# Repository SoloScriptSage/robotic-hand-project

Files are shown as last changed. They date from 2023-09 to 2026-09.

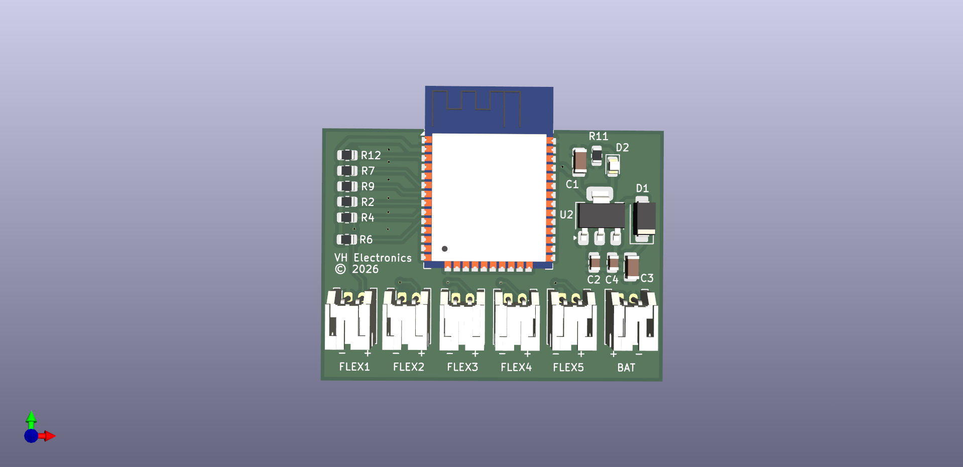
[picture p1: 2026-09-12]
hardware/schematics/transmitter/robotic_hand.png

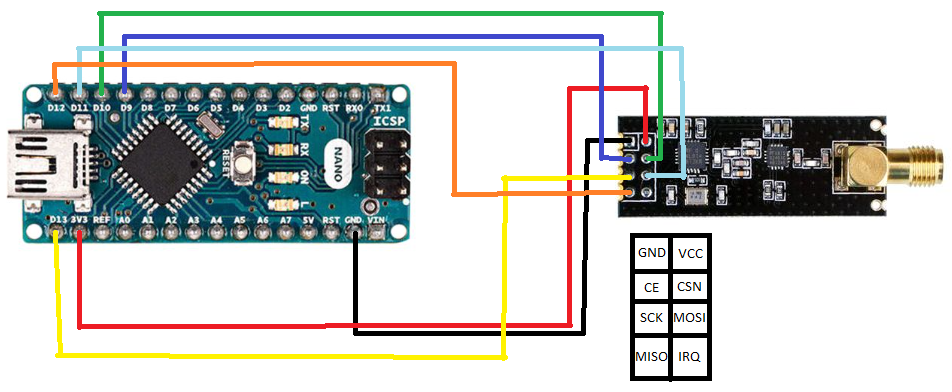
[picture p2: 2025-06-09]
hardware/assembly-guides/nrf-arduino-nano.png

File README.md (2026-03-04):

# 🤖 Robotic Hand Project

A wireless gesture-controlled robotic hand built with Arduino, flex sensors, and NRF24L01 radio modules. A glove fitted with flex sensors captures hand movements and transmits them wirelessly to a 3D-printed robotic hand, which mirrors the gestures in real time via servo motors.

Originally developed as an open-source prosthetic research platform.

---

## 📸 Demo

Robotic Hand Demo

---

## ✨ Features

- Real-time wireless gesture control via NRF24L01 (250KBPS, ~100m range)
- 5-finger articulation using MG996R servo motors
- Flex sensor glove for intuitive hand tracking
- Per-finger calibration support
- Simple, hackable codebase — easy to extend

---

## 📁 Repository Structure

```
robotic-hand-project/
│
├── firmware/
│   ├── transmitter/        ← glove Arduino code
│   ├── receiver/           ← hand Arduino code
│   ├── test_sensors/       ← flex sensor calibration helper
│   └── servo_test/         ← servo sweep test
│
├── hardware/
│   ├── schematics/         ← wiring diagrams
│   ├── pcb/                ← PCB files
│   ├── mechanical/
│   │   └── robotic-hand-stls/  ← 3D print files
│   ├── assembly-guides/    ← step by step assembly
│   ├── datasheets/         ← component datasheets
│   └── BOM.md              ← full bill of materials
│
├── docs/
│   ├── calibration.md      ← flex sensor calibration guide
│   └── troubleshooting.md  ← common issues and fixes
│
├── images/                 ← photos and demo gifs
├── .gitignore
├── LICENSE
└── README.md
```

---

## 🛠️ Materials

Full bill of materials with component links and prices → [`hardware/BOM.md`](hardware/BOM.md)

---

## 🗺️ Schematics

Wiring diagrams for both transmitter and receiver → [`hardware/schematics/`](hardware/schematics/)

> ⚠️ Power the NRF24L01 modules from the **3.3V pin only** — they are not 5V tolerant.

---

## 🖨️ 3D Model

The hand structure is sourced from [Viral Science](https://www.viralsciencecreativity.com/post/arduino-flex-sensor-controlled-robot-hand). Print files are available in [`hardware/mechanical/robotic-hand-stls/`](hardware/mechanical/robotic-hand-stls/).

Print settings:
- Material: PLA or PETG
- Infill: 20–30%
- Supports: Yes (for finger joints)

---

## ⚙️ Setup

### 1. Clone the repository
```bash
git clone https://github.com/SoloScriptSage/robotic-hand-project.git
```

### 2. Install Arduino libraries
In Arduino IDE go to **Sketch → Include Library → Manage Libraries** and install:
- `RF24` by TMRh20
- `Servo` (built-in)

### 3. Assemble the hardware
- Print and assemble the 3D hand following the guides in [`hardware/assembly-guides/`](hardware/assembly-guides/)
- Wire flex sensors to the glove according to the schematics
- Wire servos to the receiver board according to the schematics

### 4. Calibrate the flex sensors
Follow the step-by-step guide → [`docs/calibration.md`](docs/calibration.md)

### 5. Flash the firmware
- Flash [`firmware/transmitter/transmitter.ino`](firmware/transmitter/transmitter.ino) to the **glove Arduino**
- Flash [`firmware/receiver/receiver.ino`](firmware/receiver/receiver.ino) to the **hand Arduino**

### 6. Test
- Flash [`firmware/servo_test/servo_test.ino`](firmware/servo_test/servo_test.ino) to verify all servos sweep correctly
- Power both Arduinos and open Serial Monitor — you should see sensor values on the transmitter and matching received values on the receiver

---

## 💻 Code Overview

| File | Description |
|---|---|
| `transmitter.ino` | Reads flex sensors, maps to servo angles, transmits via NRF24L01 |
| `receiver.ino` | Receives data, writes angles to servo motors |
| `test_sensors.ino` | Prints raw flex sensor values for calibration |
| `servo_test.ino` | Sweeps all servos 0→180→0 for hardware testing |

---

## 🧪 Testing

Sensor Testing
Bending Testing

---

## 📖 Docs

- [Calibration Guide](docs/calibration.md)
- [Troubleshooting](docs/troubleshooting.md)

---

## 🚀 Roadmap

- [ ] Per-finger calibration via Serial Monitor wizard
- [ ] Haptic feedback on glove (vibration motors)
- [ ] NRF24L01 external antenna for extended range
- [ ] Replace flex sensors with IMU-based gesture recognition
- [ ] Full prosthetic enclosure design
- [ ] Support for wrist rotation (6th servo)

---

## 🙏 Acknowledgments

- [Viral Science](https://www.viralsciencecreativity.com/post/arduino-flex-sensor-controlled-robot-hand) for the 3D hand model
- [TMRh20](https://github.com/nRF24/RF24) for the RF24 library
- The open-source Arduino community

---

## 📄 License

This project is open-source under the [MIT License](LICENSE).

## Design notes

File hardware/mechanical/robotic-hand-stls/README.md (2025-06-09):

# 🖨️ Robotic Hand – STL Files

This folder contains the 3D printable parts (STL format) used to assemble the robotic hand mechanism.

---

## 📁 Included Files

| File Name | Description |
|---|---|
| `Arm.stl` | Forearm base part |
| `Arm_Cover.stl` | Cover or mount for forearm |
| `Finger_Thumb.stl` | Thumb finger segment |
| `Finger_Index.stl` | Index finger segment |
| `Finger_Middle.stl`  | Middle finger segment |
| `Finger_Ring.stl` | Ring finger segment |
| `Finger_Pinky.stl` | Pinky finger segment |
| `Left_Hand.stl` | Complete left hand model |
| `Right_Hand.stl` | Complete right hand model  |

> 🔒 `.DS_Store` is a macOS system file and can be ignored or deleted.

---

## 📥 Credit & Attribution

The mechanical design of the robotic hand was sourced from **Viral Science**.

🔗 [Arduino Flex Sensor Controlled Robotic Hand – Viral Science](https://www.viralsciencecreativity.com/post/arduino-flex-sensor-controlled-robot-hand)

We give full credit to the Viral Science team for sharing their design with the maker community. This STL collection is redistributed here for educational and prototyping purposes.

---

## 🛠️ Printing & Assembly Tips

- **Material:** PLA or PETG recommended
- **Infill:** 30–50% for durability
- **Supports:** Use if needed (especially for fingers)
- **Scale:** Ensure correct scale before printing
- **Assembly:** Use fish wire to connect fingers to servo horns; secure with a glue gun where necessary

---

## 🧠 Integration

These mechanical parts are designed to be used with:

- **MG996R Servo Motors**
- **Arduino Nano**
- **NRF24L01 wireless modules**
- **Flex sensors**

Refer to the main project’s BOM and wiring diagrams for details.

---

**Note:** All mechanical parts should be tested and tweaked for fit with your specific hardware and 3D printer tolerances.

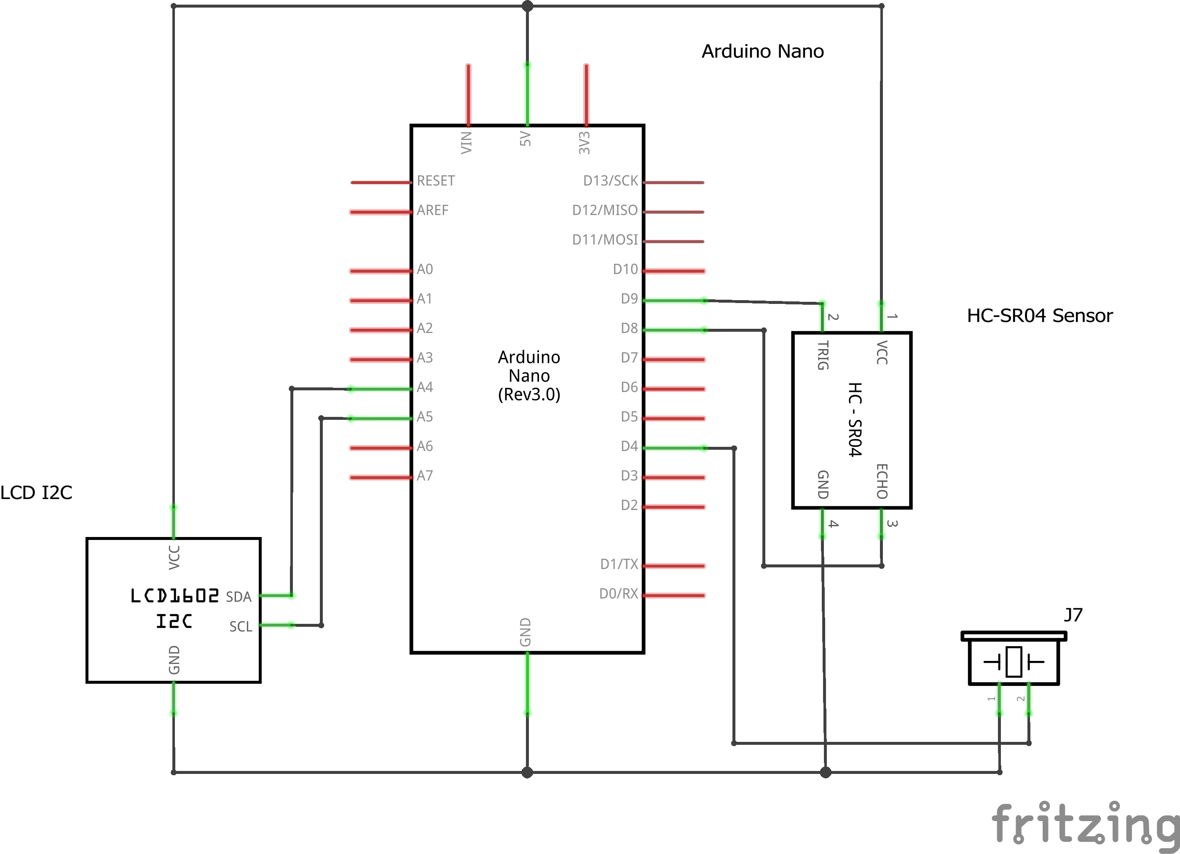
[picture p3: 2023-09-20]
images/distance_schematic.jpg

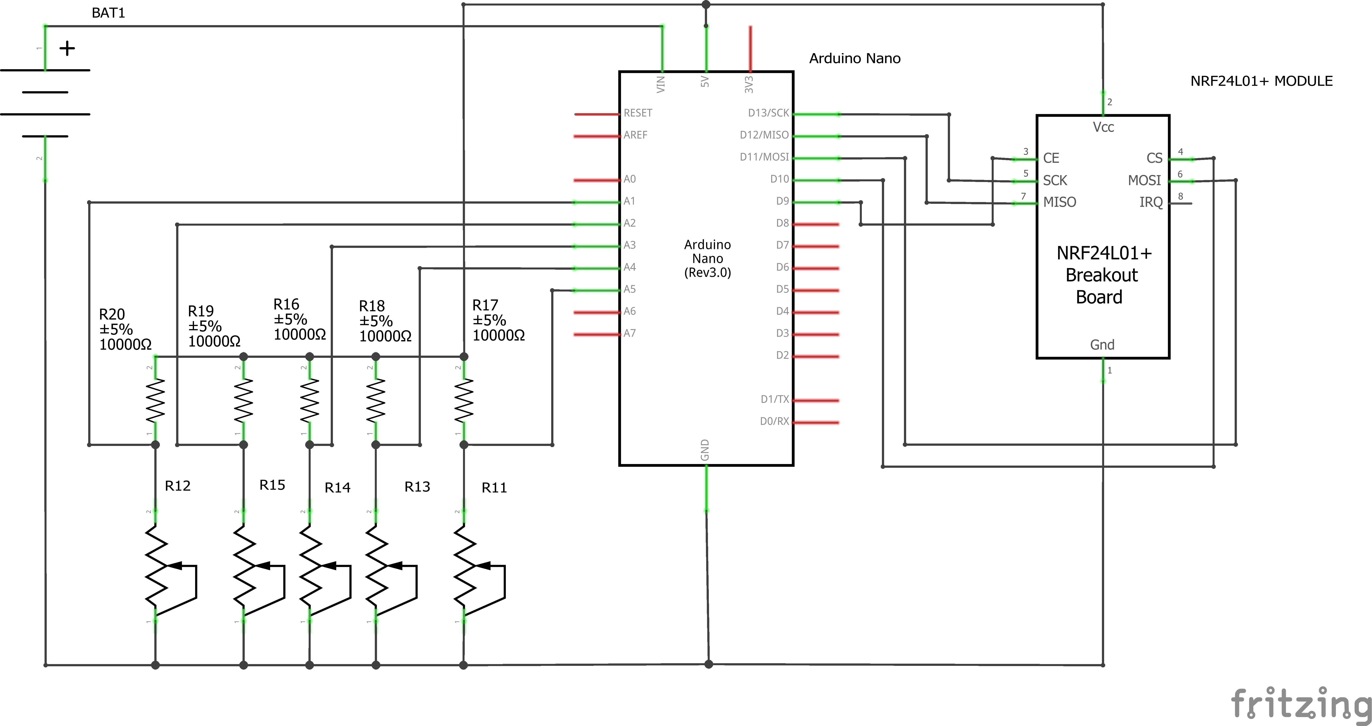
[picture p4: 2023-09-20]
images/transmitter_schematic.png

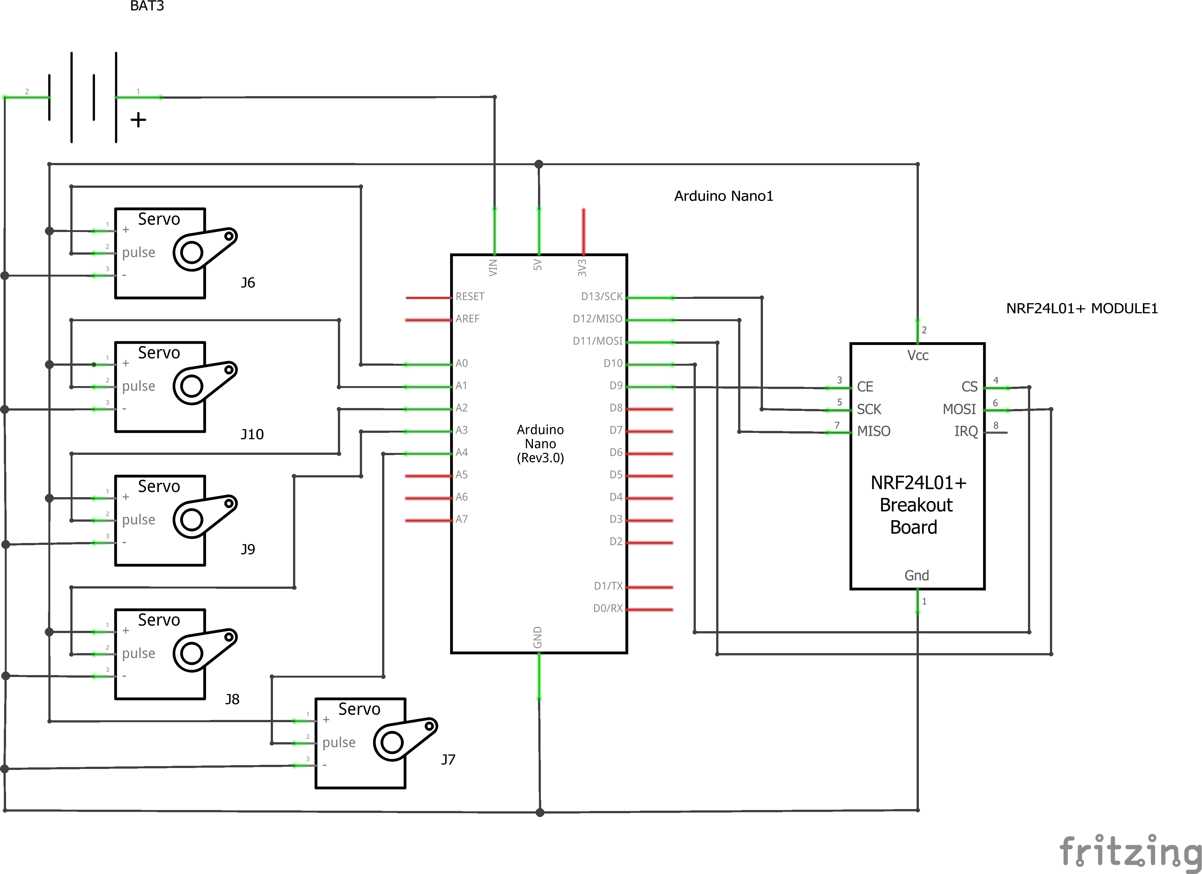
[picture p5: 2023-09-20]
images/receiver_schematic.jpg

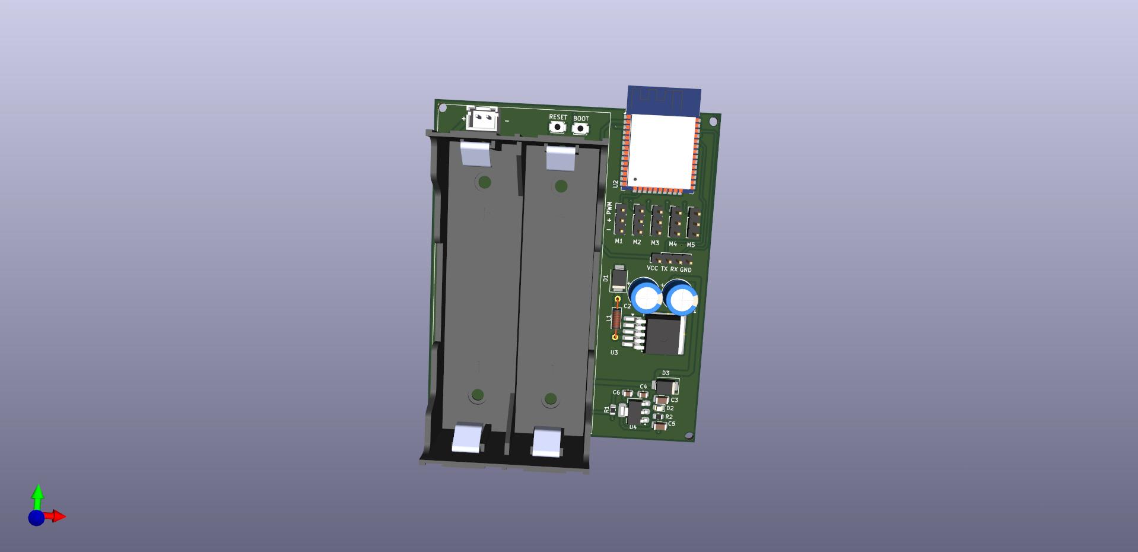
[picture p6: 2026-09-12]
hardware/schematics/reciever/robotic_hand_recievier.jpg

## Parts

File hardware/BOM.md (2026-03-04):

# Bill of Materials

Full component list for the robotic hand project. Includes both the glove (transmitter) and the robotic hand (receiver).

---

## Electronics

| # | Component | Description | Qty | Unit Price (est.) | Link |
|---|---|---|---|---|---|
| 1 | Arduino Uno / Mega | Microcontroller — one for glove, one for hand | 2 | ~$10 | [Amazon](https://a.co/d/7hcBaU4) |
| 2 | NRF24L01+ Module | 2.4GHz wireless transceiver | 2 | ~$2 | [Amazon](https://a.co/d/2pLEXYt) |
| 3 | Flex Sensor 2.2" | Bend-sensitive resistor for each finger | 5 | ~$8 | [Amazon](https://a.co/d/0HHEU9b) |
| 4 | MG996R Servo Motor | High-torque servo for finger actuation | 5 | ~$5 | [Amazon](https://a.co/d/9qywIPb) |
| 5 | 10kΩ Resistor | Pull-down resistor for flex sensor voltage divider | 5 | ~$0.10 | [Amazon](https://a.co/d/1EXjHHf) |
| 6 | LiPo 7.4V / NiMH 7.2V Battery | Power supply for servo side | 1 | ~$15 | [Amazon](https://a.co/d/2NYQ9gW) |
| 7 | Jumper Wires | M-M and M-F for connections | 1 set | ~$5 | [Amazon](https://a.co/d/2u9a7ZK) |

---

## Mechanical

| # | Component | Description | Qty | Link |
|---|---|---|---|---|
| 1 | 3D Printed Hand Parts | STL files in [`hardware/mechanical/robotic-hand-stls/`](mechanical/robotic-hand-stls/) | 1 set | — |
| 2 | Fish Wire | Finger tendon line | ~1m | [Amazon](https://a.co/d/iEQPEsA) |
| 3 | Hot Glue | For securing components | — | [Amazon](https://a.co/d/2u9a7ZK) |
| 4 | M2/M3 Screws | For mounting servos to hand frame | ~20 | — |

---

## Tools Required

| Tool | Notes |
|---|---|
| 3D Printer | PLA or PETG recommended |
| Soldering Iron | For secure sensor connections |
| Hot Glue Gun | For cable management and securing parts |
| Multimeter | For troubleshooting connections |
| Arduino IDE | Version 2.x recommended |

---

## Notes

- NRF24L01 modules must be powered from **3.3V**, not 5V
- MG996R servos draw significant current — power them from the battery directly, not from Arduino 5V
- A capacitor (100µF) across the NRF24L01 power pins helps stabilize the module

---

*Schematics are available in [`hardware/schematics/`](schematics/)*

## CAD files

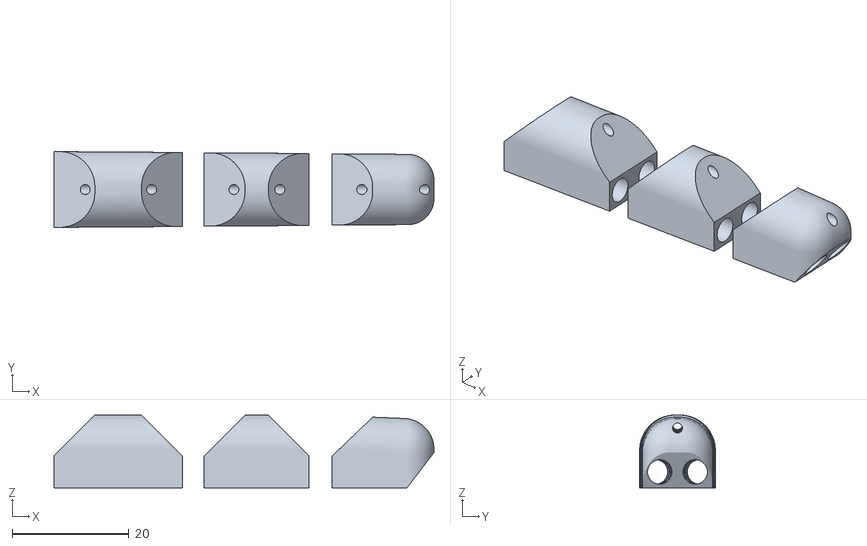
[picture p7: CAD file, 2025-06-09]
hardware/mechanical/robotic-hand-stls/Finger_Pinky.stl
65.2 x 13.0 x 12.5

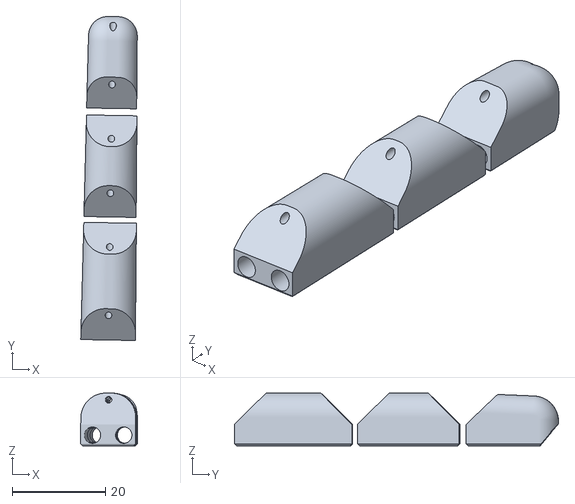
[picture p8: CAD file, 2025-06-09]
hardware/mechanical/robotic-hand-stls/Finger_Index.stl
12.1 x 69.4 x 11.3

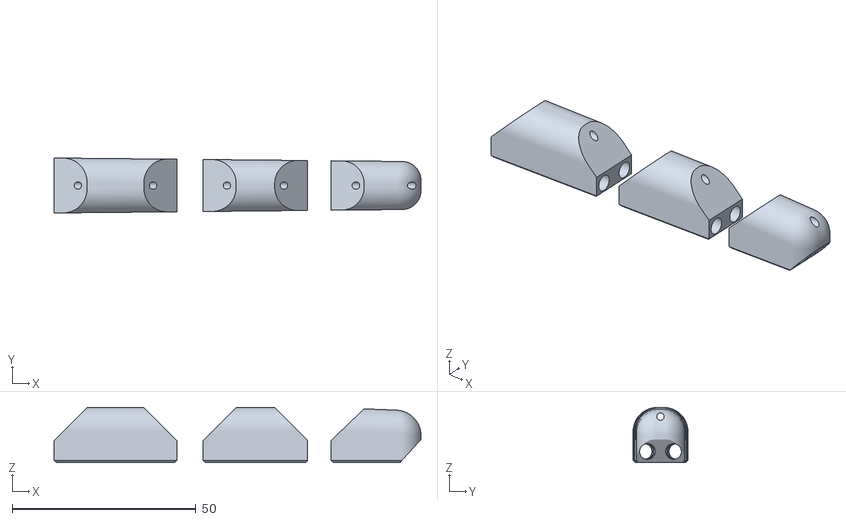
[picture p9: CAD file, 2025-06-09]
hardware/mechanical/robotic-hand-stls/Finger_Middle.stl
100.0 x 15.0 x 15.0

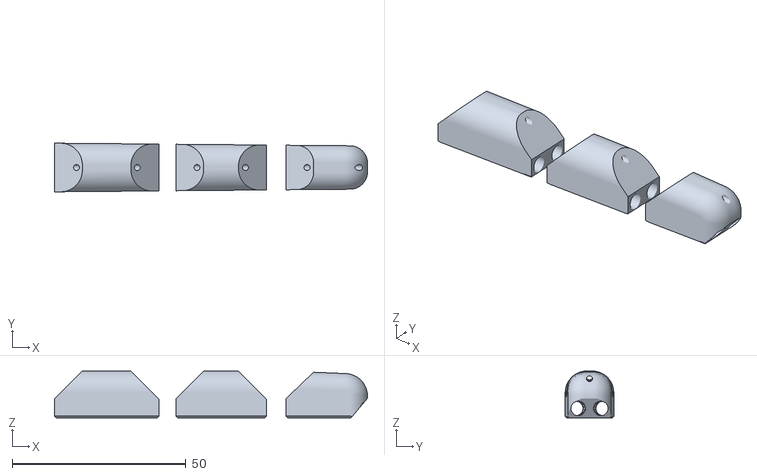
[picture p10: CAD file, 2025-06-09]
hardware/mechanical/robotic-hand-stls/Finger_Ring.stl
90.0 x 14.0 x 13.5

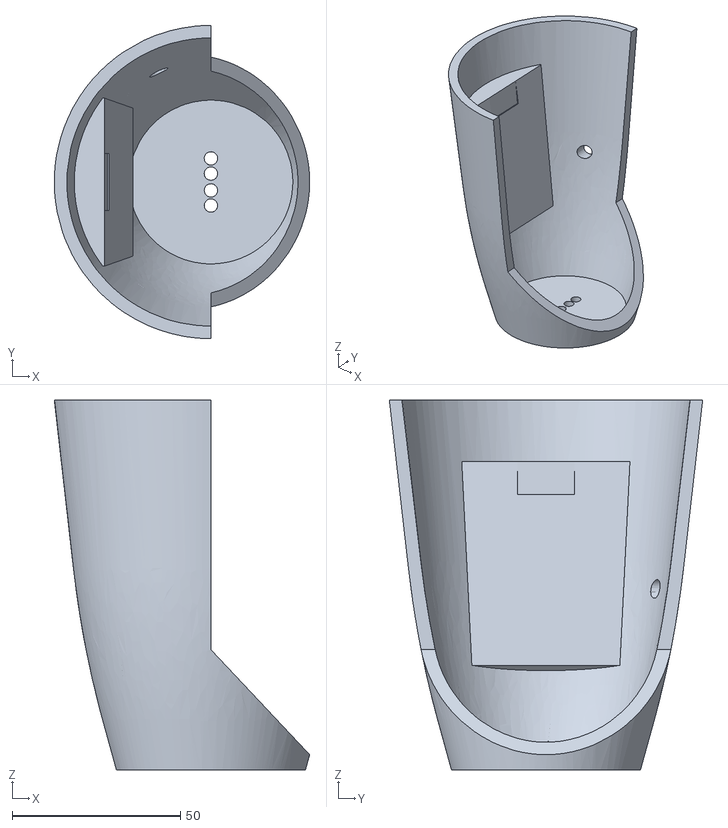
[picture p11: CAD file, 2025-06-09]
hardware/mechanical/robotic-hand-stls/Arm.stl
75.9 x 93.1 x 109.9

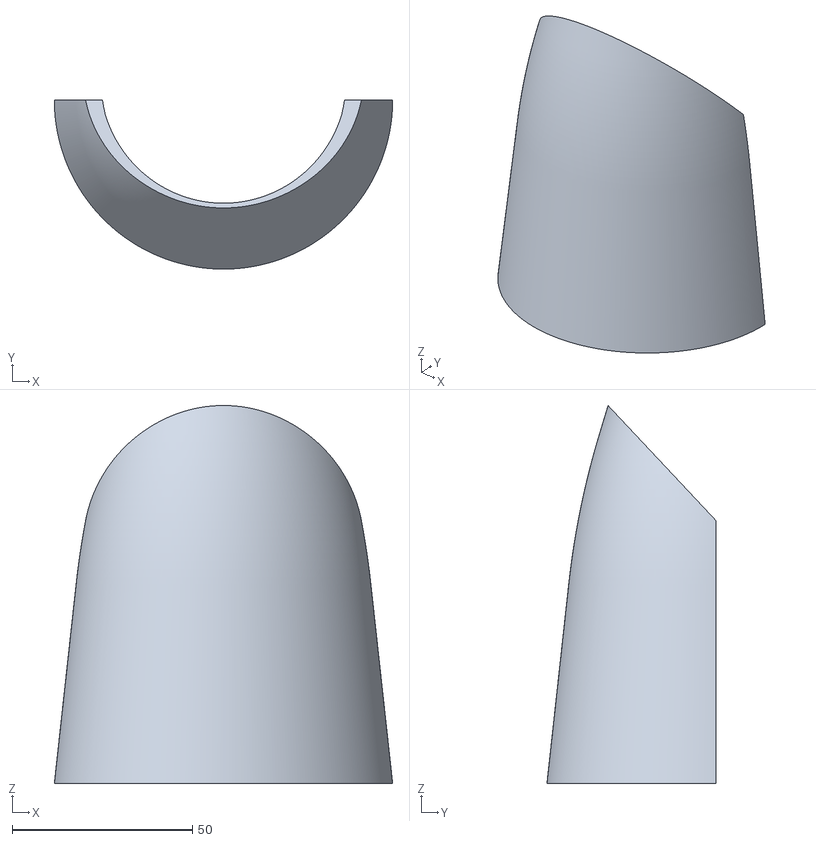
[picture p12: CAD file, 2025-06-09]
hardware/mechanical/robotic-hand-stls/Arm_Cover.stl
94.0 x 47.0 x 105.0

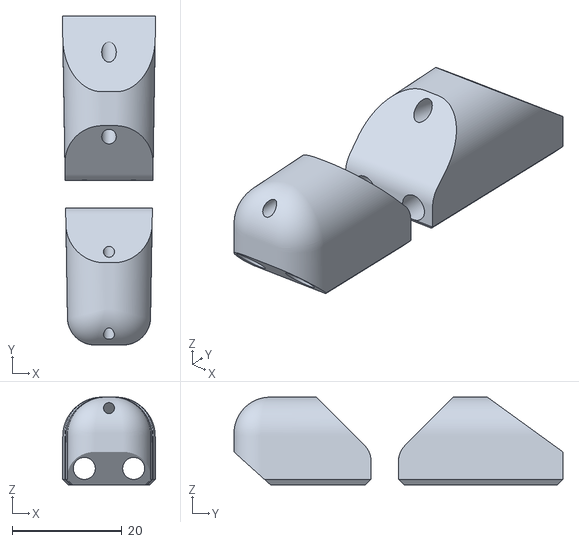
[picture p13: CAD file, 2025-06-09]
hardware/mechanical/robotic-hand-stls/Finger_Thumb.stl
17.0 x 60.0 x 16.0

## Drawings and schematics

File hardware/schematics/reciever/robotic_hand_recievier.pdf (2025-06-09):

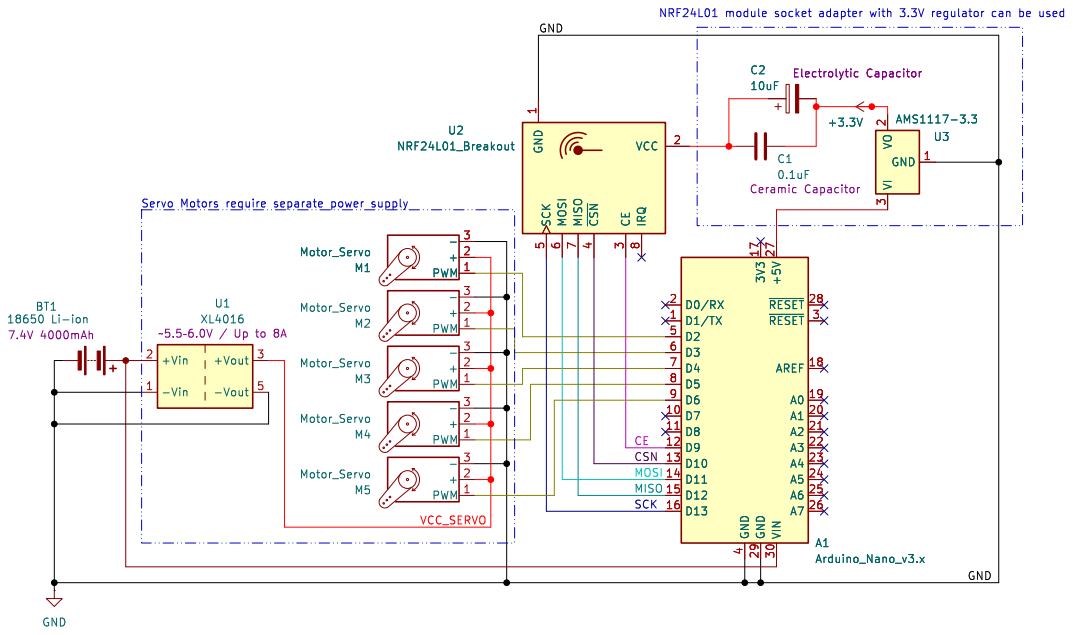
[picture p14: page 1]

SCK MOSI CECSN GND

github.com/SoloScriptSage/robotic-hand-project

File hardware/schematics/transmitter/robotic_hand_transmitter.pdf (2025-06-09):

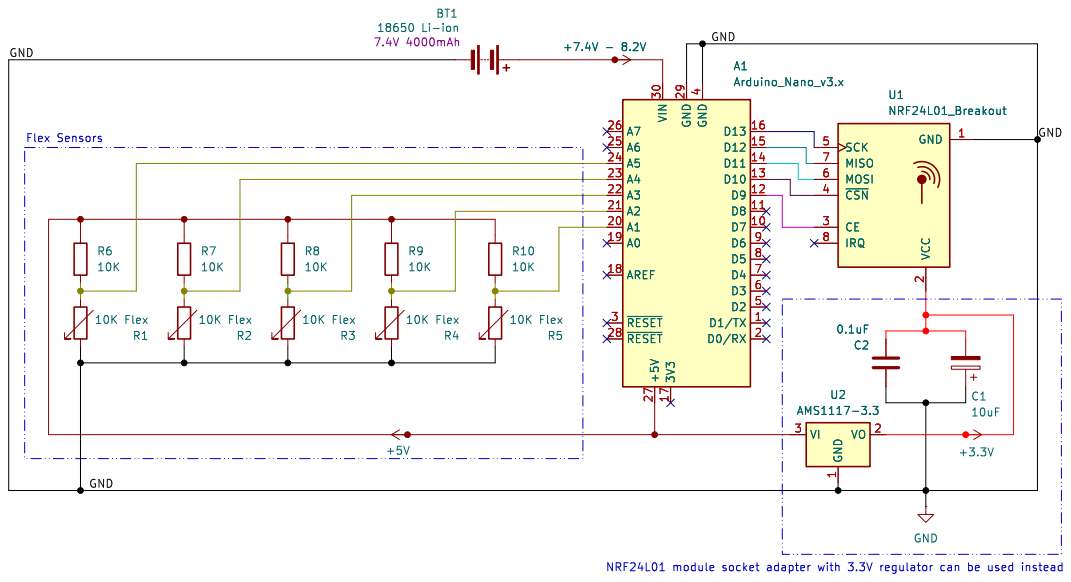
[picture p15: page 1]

Id: 1/1 Title: Robotic Hand Transmitter File: robotic_hand.kicad_sch Sheet: / SoloScriptSage R1

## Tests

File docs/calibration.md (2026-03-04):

# Flex Sensor Calibration Guide

Each flex sensor behaves slightly differently depending on its physical properties and how it is mounted on the glove. This guide walks you through measuring the real min/max values for each finger and updating the firmware accordingly.

---

## What You Need

- Transmitter Arduino (glove side)
- USB cable connected to your PC
- Arduino IDE with Serial Monitor
- `test_sensors.ino` flashed to the transmitter Arduino

---

## Step 1 — Flash the Test Sketch

Open `firmware/test_sensors/test_sensors.ino` in Arduino IDE and upload it to the **transmitter Arduino** (glove side).

---

## Step 2 — Open Serial Monitor

In Arduino IDE go to **Tools → Serial Monitor** and set the baud rate to **9600**.

You should see output like this every 500ms:
```
F1: 537    F2: 540    F3: 533    F4: 538    F5: 535
```

---

## Step 3 — Record Flat Values (FLEX_MIN)

Hold your hand **completely flat and relaxed** — do not bend any fingers.

Wait a few seconds for the readings to stabilize, then record the value for each finger:

| Finger | Pin | Flat Value (your reading) |
|---|---|---|
| F1 (thumb) | A1 | |
| F2 (index) | A2 | |
| F3 (middle) | A3 | |
| F4 (ring) | A4 | |
| F5 (pinky) | A5 | |

---

## Step 4 — Record Bent Values (FLEX_MAX)

Curl each finger **fully** into a fist, one at a time, while watching the Serial Monitor.

Record the maximum value reached for each finger:

| Finger | Pin | Bent Value (your reading) |
|---|---|---|
| F1 (thumb) | A1 | |
| F2 (index) | A2 | |
| F3 (middle) | A3 | |
| F4 (ring) | A4 | |
| F5 (pinky) | A5 | |

---

## Step 5 — Update the Firmware

Open `firmware/transmitter/transmitter.ino` and update `FLEX_MIN` and `FLEX_MAX` with your recorded values:

```cpp
// Replace these with your actual measured values
const int FLEX_MIN[5] = {537, 540, 533, 538, 535}; // flat
const int FLEX_MAX[5] = {680, 695, 672, 688, 710}; // fully bent
```

The order is: `{F1, F2, F3, F4, F5}` → `{thumb, index, middle, ring, pinky}`

---

## Step 6 — Verify

Flash the updated `transmitter.ino` and open Serial Monitor again. Now the output should show values between **1 and 180** instead of raw ADC values:

```
Sensors: 1    1    1    1    1       ← hand flat
Sensors: 180  175  170  180  168     ← fist
```

If a finger reads 180 even when flat, or 1 even when fully bent — swap the min and max values for that finger.

---

## Tips

- Redo calibration if you remount the sensors on the glove
- If readings are noisy, add a small capacitor (10–100nF) between the sensor pin and GND
- `constrain()` in the code will clamp any out-of-range values so the servos won't go past their limits

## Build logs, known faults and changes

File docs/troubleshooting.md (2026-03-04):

# Troubleshooting Guide

Common issues and fixes for the robotic hand project.

---

## 🤚 Hand Not Moving At All

**1. Check the radio connection first**

Open Serial Monitor on the receiver Arduino. If you see nothing printed, the radio is not receiving.

- Make sure both NRF24L01 modules are powered from **3.3V not 5V**
- Add a 100µF capacitor across the VCC and GND pins of each NRF24L01 — power instability is the most common cause of radio failure
- Confirm both modules are on the same channel (`0x60`) and same data rate (`RF24_250KBPS`)
- Try swapping the transmitter and receiver modules — one may be faulty

**2. Check the servo power**

Servos must be powered from the battery directly, not from the Arduino 5V pin. Five MG996R servos under load will draw more current than the Arduino can supply and will cause resets or no movement.

---

## 📡 Intermittent or Dropped Connection

- Add the 100µF capacitor across NRF24L01 power pins if not already done
- Keep the modules away from motors and power wires — interference is common
- Try `radio.setPALevel(RF24_PA_LOW)` at short range — max power can cause reflections indoors
- Make sure antennas on both modules are not obstructed or touching metal

---

## 🖐️ Fingers Move in Wrong Direction

The `map()` function in `transmitter.ino` maps flat→bent to 1→180. If a finger moves backwards, swap the min and max for that finger:

```cpp
// Before (backwards)
const int FLEX_MIN[5] = {535, 535, 535, 535, 535};
const int FLEX_MAX[5] = {680, 680, 680, 680, 710};

// After (swap values for the affected finger, e.g. F2)
const int FLEX_MIN[5] = {535, 680, 535, 535, 535};
const int FLEX_MAX[5] = {680, 535, 680, 680, 710};
```

---

## 🤖 Servos Jitter or Stutter

- Power the servos from the battery with a common GND shared with the Arduino
- Add a 100µF capacitor across each servo's power pins
- Increase the `constrain()` range slightly if values are bouncing near the edges
- Check for loose connections on servo signal wires

---

## 📊 Sensor Readings Are Noisy

- Add a 10–100nF ceramic capacitor between each flex sensor analog pin and GND
- Slow down the `analogRead()` sampling — add a small `delay(10)` between reads
- Make sure the 10kΩ pull-down resistors are properly connected

---

## 🔢 Sensor Values Don't Change When Bending

- Check the voltage divider wiring — the flex sensor and 10kΩ resistor must form a divider between 5V and GND
- Measure voltage across the sensor with a multimeter while bending — it should change
- The sensor itself may be broken — test resistance with a multimeter (should change from ~10kΩ flat to ~40kΩ bent)

---

## 💻 Upload Fails in Arduino IDE

- Make sure the correct board and COM port are selected under **Tools**
- Only one Serial Monitor can be open at a time — close it before uploading
- If using Arduino Mega, CE and CSN pins may differ — check your wiring against the schematic

---

## 🔋 Arduino Keeps Resetting

- Servos are drawing too much current from Arduino 5V — power them directly from the battery
- Check for short circuits in wiring
- Make sure GND is shared between Arduino and battery

---

## Still Stuck?

1. Flash `firmware/test_sensors/test_sensors.ino` and verify flex sensors respond in Serial Monitor
2. Flash `firmware/servo_test/servo_test.ino` and verify all servos sweep correctly
3. If both work independently but not together, the issue is in the radio link

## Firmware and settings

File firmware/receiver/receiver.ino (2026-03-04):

#include <SPI.h>
#include <nRF24L01.h>
#include <RF24.h>
#include <Servo.h>

RF24 radio(9, 10);

const byte address[][6] = {"1Node", "2Node", "3Node", "4Node", "5Node", "6Node"};

Servo servos[5];
const int SERVO_PINS[5] = {2, 3, 4, 5, 6};

int gotByte[5];

void setup() {
    Serial.begin(9600);

    radio.begin();
    radio.setAutoAck(true);
    radio.setRetries(3, 15);
    radio.enableAckPayload();
    radio.setPayloadSize(sizeof(gotByte));
    radio.openReadingPipe(1, address[0]);
    radio.setChannel(0x60);
    radio.setPALevel(RF24_PA_MAX);
    radio.setDataRate(RF24_250KBPS);
    radio.powerUp();
    radio.startListening();

    for (int i = 0; i < 5; i++) {
        servos[i].attach(SERVO_PINS[i]);
        servos[i].write(90); // center position on startup
    }
}

void loop() {
    byte pipeNo;
    if (radio.available(&pipeNo)) {
        radio.read(&gotByte, sizeof(gotByte));

        Serial.print("Received: ");
        for (int i = 0; i < 5; i++) {
            gotByte[i] = constrain(gotByte[i], 1, 180);
            servos[i].write(gotByte[i]);
            Serial.print(gotByte[i]);
            Serial.print("\t");
        }
        Serial.println();
    }
}

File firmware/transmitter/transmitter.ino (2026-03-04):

#include <SPI.h>
#include <nRF24L01.h>
#include <RF24.h>

RF24 radio(9, 10);

const byte address[][6] = {"1Node", "2Node", "3Node", "4Node", "5Node", "6Node"};

const int FLEX_PINS[5] = {A1, A2, A3, A4, A5};

// TODO: Replace with real values from test_sensors.ino
// Bend each finger flat and fully bent, record the Serial Monitor values
const int FLEX_MIN[5] = {535, 535, 535, 535, 535}; // flat (unflexed)
const int FLEX_MAX[5] = {680, 680, 680, 680, 710}; // fully bent

int msg[5];

void setup() {
    Serial.begin(9600);

    radio.begin();
    radio.setAutoAck(true);
    radio.setRetries(3, 15);
    radio.enableAckPayload();
    radio.setPayloadSize(sizeof(msg));
    radio.openWritingPipe(address[0]);
    radio.setChannel(0x60);
    radio.setPALevel(RF24_PA_MAX);
    radio.setDataRate(RF24_250KBPS);
    radio.powerUp();
    radio.stopListening();
}

void loop() {
    for (int i = 0; i < 5; i++) {
        int raw = analogRead(FLEX_PINS[i]);
        msg[i] = constrain(map(raw, FLEX_MIN[i], FLEX_MAX[i], 1, 180), 1, 180);
    }

    Serial.print("Sensors: ");
    for (int i = 0; i < 5; i++) {
        Serial.print(msg[i]);
        Serial.print("\t");
    }
    Serial.println();

    radio.write(&msg, sizeof(msg));
    delay(50);
}

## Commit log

2025-06-09 Create assembly-guides
2025-06-09 Create cad-models
2026-03-04 Refactor transmitter code for flex sensor handling
    [transmitter.ino]
2026-03-04 Refactor flex sensor readings to use array
    Refactored sensor reading code to use an array for flex pins.
2026-03-04 Simplify servo control using an array
    Refactored servo control to use an array for better scalability.
2026-03-04 Refine flex sensor values and radio settings
    Updated FLEX_MIN and FLEX_MAX values for better accuracy. Adjusted radio retry settings.
    [transmitter.ino]
2026-03-04 Create .gitignore for build artifacts and IDE files
    Add common ignore patterns for Arduino, IDE, and OS files.
2026-03-04 Add test_sensors.ino for sensor testing
2026-03-04 Restructure repo: fix firmware, add BOM, calibration and troubleshooting docs, update README
2026-09-12 Expand schematics and add initial PCB layouts for both boards
    [robotic_hand.kicad_pcb, robotic_hand.kicad_sch, robotic_hand_recievier.kicad_pcb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]
2026-09-12 Ignore KiCad autosaves, footprint cache and local project state
2026-09-12 Revert schematics to rev-A Arduino design; ESP32 redesign split to separate project
    [robotic_hand.kicad_pcb, robotic_hand.kicad_sch, robotic_hand_recievier.kicad_pcb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]
2026-09-12 Untrack KiCad local project state files
